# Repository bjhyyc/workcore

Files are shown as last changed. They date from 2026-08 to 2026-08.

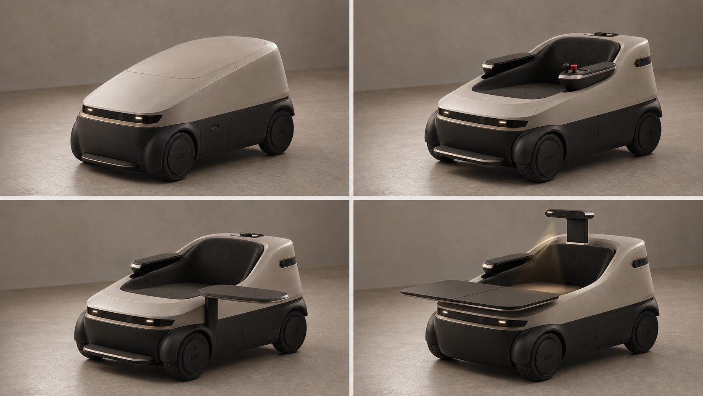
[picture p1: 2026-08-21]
design/e6_final_exterior/renders/02_four_state_board.png

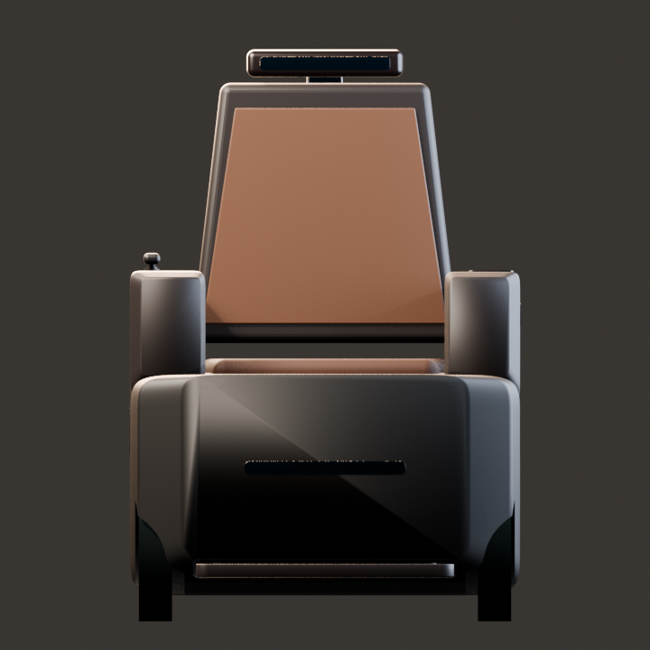
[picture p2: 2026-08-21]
design/e6_final_exterior/v11_v8_blender_exterior_restart_20260721/renders/preview/r14/ride/ride_front.png

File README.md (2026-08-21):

# WorkCore engineering CAD baseline

This repository converts the v30 and v37 WorkCore HTML concepts into a
parametric B-Rep CAD and system-engineering baseline. The generated STEP files
are intended for prototype engineering review and supplier discussion. They are
**not release-to-tool** drawings until the open assumptions, load cases,
tolerances, electrical architecture and safety analyses are signed off.

## Coordinate system

- Units: millimetres
- X: front/rear; negative X is the front/foot side
- Y: left/right; positive Y is the right side
- Z: height; Z=0 is the floor plane
- Assembly origin: floor projection of the chassis datum centre

## Build

```powershell
.\build.ps1 -Stage model
```

The wrapper requires Python 3.12, checks the CAD/runtime imports, rebuilds the
artifact set, then verifies its hashes and the requested gate. Use `-Stage evt0`,
`human`, `dvt`, `pvt` or `mp` only when intentionally testing that gate; a
non-zero result is expected while its evidence remains open.

Each build uses an empty `.build-staging/<run_id>/build` tree, so an old file
cannot satisfy a missing output. Publication is a journaled logical transaction:
the public status stays `PUBLISHING` while managed files are atomically replaced,
the manifest and hash-bound `COMPLETE` status are committed last, and a dead
publisher is rolled back before a later run proceeds. Unknown files under
`build/` are never deleted or packaged; the verifier reports them recursively.

Outputs are written to `build/`:

- `workcore_stowed.step` — transport configuration
- `workcore_follow_closed.step` — empty folded restricted-follow configuration with the restored v37 base sensor suite
- `workcore_obstacle_assist.step` — v37-derived rear pull handle extended with the unoccupied chassis pitched 8°
- `workcore_seat_ready.step` — occupied-ready seat and deployed footrest
- `workcore_cafe.step` — parked social configuration with one desk half deployed and the opposite side open
- `workcore_internal_layout.step` — shells removed for battery/data/compute/drawer review
- `workcore_transfer_ready.step` — right-side swing-away transfer configuration
- `workcore_desk.step` — forward-deploying dual-panel desk configuration with armrest lids closed
- `workcore_canopy_deployed.step` — canopy configuration
- `workcore_*.glb` — lightweight visual review models
- `workcore_desk_occupied_review.glb` — product plus clothed human keep-out model
- `workcore_e6_review.html` — single-file interactive four-state product and engineering review page
- `workcore_e4_review.html` — compatibility copy for existing bookmarks, presenting the same E6 review
- `workcore_e4_review_offline.html` — cache-busting, fully offline copy with embedded Three.js runtime
- `workcore_storage_review.glb` — dedicated shell-free equipment-bay review scene
- `workcore_storage_wheel_review.glb` — equipment-bay and wheel/suspension clearance context
- `workcore_electrical_thermal_review.glb` — electrical modules, PDU partitions, harness zones and heat-rejection context
- `parts/*.step` — supplier-facing individual solids
- `bom.csv` — material/process/mass estimate
- `production_bom.csv` — candidate configuration-union catalogue; not a released EBOM, purchasing list or unit-mass source
- `cots_interface_register.csv` — candidate supplier parts and controlled envelopes
- `tolerance_register.csv` — production-critical clearances and adjustment margins
- `validation.json` — geometry and clearance checks
- `engineering_report.json` — stability, wind, structure, actuator and load checks
- `mobility_report.json` — zero-turn, obstacle, access, elevator and trunk analysis
- `power_thermal_report.json` — traction/device power, energy, runtime, harness voltage-drop and airflow checks
- `production_readiness_report.json` — design-freeze evidence index, P0 gates and stage decisions
- `requirements_traceability.csv` — product, safety, usability and production requirements with evidence status
- `risk_register.csv` — system hazard register and required control verification
- `dvpr.csv` — EVT/DVT/PVT design-verification plan and acceptance intent
- `supplier_release_register.csv` — critical commodity selection and supplier-quality gates
- `production_gate_checklist.csv` — G0 through mass-production release checklist
- `access_scenarios.csv` — door and vehicle-template fit matrix
- `build_status.json` — generation state; interrupted/failed output is never packageable
- `release_manifest.json` — source/environment/artifact hashes, check split and stage decisions
- `preview_*.png` — rendered review images

## Engineering status

E6R2 is the current product-definition and CAD baseline. It restores the original
v37 folded follow-perception architecture as production-aware internal modules,
optical/RF/acoustic interfaces and real shell apertures. The user product has
four states: Follow, Ride, Café and Focus. Core width is now approximately
720 mm; the canopy is a detachable outdoor package; satellite communications
and onboard AC are removed; the four drawers are replaced by one 16-inch main
computer bay, one universal flat-device bay and an independent approximately
4.9 L daily-items caddy. E6R2 removes the false full-size travel cap so the
folded trapezoidal back itself becomes the weather cover, and turns the standard
right Café panel 90 degrees into a 430 x 270 mm transverse surface after the
drive pod is parked. Restricted following remains an empty, folded,
whitelisted-route Beta and is not a public-space autonomous-driving claim.

Revision E4 is a retained occupied-system geometry and safety input for East
Asian adults, not the current product baseline. E5 narrowed the launch market to
high-value knowledge workers in managed environments; its controlled B2B2C wedge
is retained by E6 while E5 product language remains design history. E4 adds closed armrest lids
in desk mode, a right swing-away transfer state, pelvic restraint, battery fire
isolation, 250 mm wheels, articulated side rockers, four-hub differential
zero-turn analysis, a 50 mm rated obstacle boundary, and door/elevator/vehicle
fit reports. Compact stow dimensions are recorded but do not override occupied
space or emergency egress.

E4-PWR1 adds a 51.2 V/30 Ah LiFePO4 design envelope, a 120 A continuous / 200 A
short-peak battery interface, separate traction and auxiliary contactors, dual
140 W USB-C PD, parked-only 600 W AC, a 90 W mast-device branch, zoned harness
routing and independent battery/electronics/laptop-bay thermal paths. All cell,
BMS, converter and fan part numbers remain supplier and prototype validation
gates.

E4-DFR1 adds physical package envelopes for the removable right-armrest drive control,
independent emergency stop, guarded charge/service-disconnect/manual-brake-release
interfaces, and an explicit production-readiness layer. The automated CAD checks
are intentionally reported separately from open regulatory, physical-test,
supplier and manufacturing gates.

E4-V37R restores three controlled features from the original v37 baseline:
the rear dual-tube obstacle-assist pull handle, the right-armrest removable
joystick/authorization pod, and the left-armrest status display plus 15 W Qi2
tray with FOD/temperature sensing. These are now CAD/BOM/validation items, not
render-only styling cues.

E5 is retained as design history but its managed-enterprise launch assumption is
superseded by E6. E5 had frozen the launch product thesis without replacing the E4 geometry baseline:
WorkCore is a personal embodied-AI work body for high-value knowledge work in
managed environments. The seat/chassis, hidden desk, asymmetric armrest HMI and
intelligence mast remain core; canopy, satellite communications, parked AC,
care claims and broad autonomy move to separately validated option packages.

The governing documents are:

- `docs/e6_product_definition_and_strategy.md` — current product constitution, four states, v37 follow-sensor restoration, storage decision, supply architecture and IP plan
- `docs/e6_launch_ecology_and_scenario_validation.md` — controlled launch wedge, real journeys, service/rescue model and pre-registered product evidence gates
- `docs/e6_object_character_and_mystery_brief.md` — new-object grammar, four-state expression, scenario behavior and falsifiable mystery/legibility gates
- `docs/configuration_control.md` — current-document precedence, evidence vocabulary and baseline rules
- `docs/configuration_mass_reconciliation.md` — pose-invariance audit, option deltas and EBOM identity closure criteria
- `docs/context_continuity_architecture.md` — measurable Context Continuity protocol, privacy boundary and EVT evidence plan
- `docs/e5_product_thesis_and_production_strategy.md` — frozen product thesis, launch scope, simplification rules, moat/IP plan and production convergence roadmap
- `docs/e4_product_definition.md` — target population, UX priorities and frozen E4 dimensions
- `docs/e4_p0_closure.md` — P0 design closures and mandatory physical release gates
- `docs/e4_access_transport_analysis.md` — elevator, shop, door and vehicle feasibility
- `docs/e4_internal_packaging_cmf.md` — laptop bay, internal modules, shells and finish maturity
- `docs/e4_power_energy_thermal_architecture.md` — complete power, energy, harness and thermal design envelope
- `docs/e4_design_freeze_readiness_review.md` — full industrial-design/NPD audit and production release sequence
- `docs/e3_human_centered_audit.md` — historical occupant-first audit and E3 findings
- `docs/v30_table_occupant_review.md` — coordinate-level review of the v30 desk
- `docs/e2_system_engineering.md` — historical E2 load boundary and prototype gates
- `docs/interface_control.md` — datums, supplier envelopes and rework controls
- `docs/safety_state_machine.md` — safe states and preliminary FMEA
- `docs/benchmark_matrix.md` — mature-product references and adoption limits

## Automated policy tests

```powershell
python -m unittest discover -s tests -v
```

These tests cover analytical units, quantity-aware mass, fail-safe motion
authority, Context Continuity privacy/safety policy, occurrence-identity rules,
controlled-overlap mutations, manifest integrity, concurrent publication,
failure rollback and dead-publisher recovery. They remain software and model
evidence only; they do not replace physical, supplier, regulatory or
manufacturing validation.

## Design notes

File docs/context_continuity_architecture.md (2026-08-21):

# WorkCore Context Continuity reference architecture

Status: E6 reference protocol and executable policy model for EVT software discovery. It is not production software, a security implementation or evidence that OS/application integration works. The reference implementation is `cad/context_continuity.py`.

## 1. Product purpose

Context Continuity is the reason WorkCore must be more than a powered chair with a folding desk. It binds an authenticated person, a known physical configuration, available devices, local task references, privacy state and optional network resources into a resumable work snapshot.

The measurable product moment is not “the mast moved”. It is:

> After the user parks and requests Focus or Café work, the correct local task becomes usable within P95 10 seconds, with no cross-user disclosure, no silent camera/microphone activation and no path from restore software to movement authority.

The 10-second target is a design input inherited from the E5 product thesis. Completeness/reliability targets must be frozen from task research before DVT; a fast but incorrect restore is a failure.

## 2. Hard boundary with movement safety

The continuity engine is outside the safety-control domain.

- It may read a hardware-certified summary such as `CAFE_PARKED` or `FOCUS_WORK`; it may not infer that state from UI intent.
- Restore is rejected unless the parking brake is confirmed, the drive contactor is open and relevant mechanisms are known and locked.
- It cannot request torque, reset STO, release brakes, move a table/mast/footrest or write safety-controller state.
- A failed, slow or compromised restore leaves the product parked. Physical escape and local manual controls do not depend on it.
- Every request and rejection is written to a tamper-evident product event stream in the production architecture.

## 3. Snapshot content and explicit exclusions

Allowed snapshot fields are opaque local workspace references, required device identities, optional network-resource references, the owner identity reference, source physical state, privacy requests, schema version and timestamp.

The snapshot must not contain plaintext credentials, encryption keys, raw biometric templates, reusable UWB secrets, safety-controller memory, arbitrary actuator commands or a serialized cloud session token. Production storage requires encryption at rest, authenticated records, per-user separation, rollback protection, retention limits and an export/delete/retirement path.

## 4. Restore sequence

1. **Authenticate owner locally.** A phone/UWB presence signal is not sufficient by itself for sensitive context release.
2. **Read the independent physical safety summary.** Unknown, moving or unlocked states reject restore.
3. **Validate snapshot schema, age and integrity.** Stale snapshots require an explicit user decision; future/invalid timestamps reject.
4. **Restore the local core first.** Network loss may remove collaborative/cloud resources but cannot erase the basic workspace.
5. **Reconnect only present, authorized devices.** Missing devices produce an explained partial restore rather than silent substitution.
6. **Apply privacy monotonicity.** The current, more private hardware state wins. A remembered camera/microphone use always requires fresh consent and visible indication.
7. **Measure and log.** Record authentication, gate result, start/useful timestamps, completeness, blocked items, user corrections and any cross-user/security event.

## 5. EVT scenario set

| Scenario | Expected result |
|---|---|
| Correct user, parked Focus, all local devices present | Full local restore; no motion request |
| Correct user, no network | Local task restores; network resources are explained as partial |
| Wrong or unauthenticated user | Reject before revealing task metadata |
| Ride/Follow/unknown mechanism state | Reject and remain parked/stopped |
| Snapshot requests camera but shutter is closed | Partial restore; shutter remains closed |
| Snapshot requests microphone without fresh consent | Partial restore; microphone stays unavailable |
| Required display/storage device missing | Partial restore naming the missing device; no silent reassignment |
| Snapshot older than the frozen retention/age boundary | Require explicit confirmation or reject |
| Power loss during snapshot write or restore | Recover last authenticated record; no corrupted half-restore |
| User export, deletion, service replacement or resale | Verifiable export/delete/crypto-erase with no recoverable prior-user context |

## 6. Required evidence

- Automated policy tests on every software change, including owner mismatch, unsafe state, stale/corrupt records, offline mode and privacy monotonicity.
- OS/device adapters tested against the frozen compatibility matrix, not merely the reference planner.
- At least one complete creator/developer task chain measured from park confirmation to useful work, with machine time separated from user cleanup/setup time.
- Repeated transition and interruption tests: sleep/wake, network switch, VPN, device removal, app update, compute-module reboot, OTA rollback and storage-full conditions.
- Threat modeling and penetration testing across phone/UWB identity, local APIs, cloud/API, debug/service ports, update and supply-chain boundaries.
- Human validation that partial restore messages answer “what is missing, why, and how to recover” without sending users into unsafe mechanism workarounds.

No claim of “context follows you” is releaseable until these tests have traceable reports and the product journey demonstrates that physical cleanup, doors, charging and recovery do not erase the promised time saving.

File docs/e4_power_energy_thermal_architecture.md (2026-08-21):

# WorkCore E4 电源、电量、线束与热管理架构

状态：E4-PWR1 工程设计包络。用于样机、电气原理图、供应商选型和测试计划；尚不是量产认证结论。

## 1. 设计结论

- 主电池：16S LiFePO4，51.2 V 标称、58.4 V 满充、30 Ah、1.536 kWh。
- 能量管理：日常按 80%（1.229 kWh）可用窗口计算，另保留 15%（230 Wh）安全/返航电量；安全控制器、通信与应急照明另有 24 V/60 Wh 独立电源。
- 主功率接口：电池 120 A 连续、200 A 短时；150 A 主熔断器；维修断电、预充、双接触器和母线电流检测必须位于电池之后、分支之前。
- 牵引：四个 250 mm 轮、25 N·m 连续和 70 N·m 峰值轮端转矩对应约 1.57 kW 连续、4.40 kW 峰值电输入。计入移动状态辅助负载后，峰值约 5.27 kW/103 A。
- 用户设备：双路 140 W USB-C PD；设备仓关闭时每路热降额至 100 W。600 W 纯正弦逆变器只允许停车态使用，以兼容 280–330 W 游戏本原厂电源。
- 外部供电：1.5 kW 外置充电器/底座，并提供岸电旁路。长时间桌面创作不应依赖加大车载电池解决。
- 桅杆：24 V/90 W 独立支路，覆盖 4K 相机、深度/红外相机、双补光灯、麦克风阵列、环境/状态传感器和网络桥；安全互锁双绞线与普通数据链路独立。
- 扶手HMI：12 V独立3 A支路，覆盖左侧5 W小屏、15 W Qi2和右侧摇杆/授权键；显示/Qi故障不得影响运动安全域。

## 2. 负载表

| 负载 | 连续/常用 | 峰值或额定包络 | 电源域 | 处理原则 |
|---|---:|---:|---|---|
| 四轮牵引 | 1.57 kW | 4.40 kW | 48V_TRACTION | 四路独立 40 A 保护；驱动故障不拖垮安全电源 |
| 双笔记本 USB-C | 200 W（仓内） | 280 W（仓开） | 48V_AUX → USB-C PD | 每仓 NTC 与风扇转速反馈；故障即停止充电 |
| 游戏本交流电源 | 0 W（移动禁用） | 600 W 逆变器 | PARKED_AC | 驻车、制动锁止并满足散热后才使能 |
| 机载计算核心 | 60–100 W | 100 W | 48V_AUX | 可覆盖 60 W 级 Jetson 模组及载板/存储/网络 |
| 通信 | 40 W | 100 W | 12V_AUX | 卫星发射突发与 5G 峰值纳入预算 |
| 桅杆小设备 | 80 W | 90 W | 24V_MAST | 7.5 A 独立保险；设备可逐级卸载 |
| 扶手小屏/Qi/控制 | 23 W | 30 W | 12V_HMI | Qi具备FOD、线圈温度和手机在位检测；过温独立停充 |
| 执行器/风扇/控制余量 | — | 300 W | 24V_AUX/12V_AUX | 动作互锁，避免与牵引峰值无约束叠加 |

桅杆 90 W 分配：4K 相机 12 W、深度/红外 15 W、两只补光灯 30 W、麦克风阵列 5 W、环境/状态传感 8 W、网络桥 10 W、设计余量 10 W。

## 3. 续航与充电

以下为 1.229 kWh 可用能量除以平均功率的工程估算，不含电池老化、低温与瞬态降额，必须用实际任务循环复测。

| 场景 | 平均功率 | 估算续航 |
|---|---:|---:|
| 安静办公 | 220 W | 5.59 h |
| 双设备创作 | 480 W | 2.56 h |
| 创作 + 间歇移动 | 650 W | 1.89 h |
| 高负载持续行驶 | 1.80 kW | 0.68 h |

1.5 kW 外置充电器按 92% 链路效率计算，10%–90% 理想能量时间约 0.89 h；含恒压收尾和温控后将产品目标定为约 1.2 h。充电口、电池接触器与岸电旁路必须互锁，禁止外部交流进入乘员可触及的低压设备仓。

## 4. 配电与保护

```text
16S LFP
  ├─ 150 A 主熔断器 ─ 维修断电 ─ 预充/双接触器 ─ 48V_TRACTION
  │                                              ├─ 4 × 40 A 电机控制器
  │                                              └─ 制动释放监控
  └─ 独立接触器 ─ 48V_AUX
                  ├─ 48→24 V / 750 W：桅杆、执行器、风扇、照明
                  ├─ 48→12 V / 240 W：通信、传感、音频
                  ├─ 双路 USB-C PD 140 W
                  └─ 600 W 纯正弦逆变器（仅停车）

24 V / 60 Wh 独立安全电源 → 安全控制器、通信、应急照明
```

负载卸载顺序：无线充电/装饰照明 → 交流逆变器 → 第二路笔记本快充 → 补光灯降亮度 → 非关键计算；牵引、制动、安全控制、最低通信和应急照明不进入普通舒适性卸载序列。

## 5. 线束路由

| 回路 | 铜截面 | 保护 | 计算压降 | 路由 |
|---|---:|---:|---:|---|
| 电池—PDU 主干 | 35 mm² | 150 A | 0.14% | 中央防护短隧道，先保险后接触器 |
| 单个轮端支路 | 6 mm² | 40 A | 0.38% | 左右门槛独立通道，轮端密封接头和滴水环 |
| 24 V 辅助主干 | 6 mm² | 35 A | 1.46% | 后部服务脊柱，星形分至桅杆、扶手和设备仓 |
| 24 V 桅杆支路 | 1.5 mm² | 7.5 A | 0.73% | 伸缩拖链，与屏蔽 Cat6A、安全互锁对线并行分仓 |

上述截面是当前长度、温升和压降的设计起点，不代替线材厂商载流量、束内降额、环境温度与连接器端子额定值。驱动电缆与麦克风/相机数据线平行时保持至少 50 mm 分隔，必须交叉时按 90°；轮端、抽屉和桅杆分别使用独立服务环，不允许靠自由垂落吸收运动。

桅杆拖链的最小动态弯曲半径按不小于成束外径 10 倍预留；样机须在全伸缩、折叠和顶棚展开的全部组合状态做夹线、拉力与视场检查。设备仓的充电线通过微型拖链进入抽屉，禁止跨越滑轨、锁舌和轮系扫掠区。

## 6. 热管理

### 电池区

电池使用密封结构盒、底部导热板和朝乘员舱外的压力泄放通道，不与乘员舱或电子仓共享空气。预设控制边界为：0°C 以下禁止充电、40°C 以上充电降额、45°C 以上禁止充电、50°C 以上牵引降额、55°C 包级停机；这些温度必须在电芯/BMS 选型后从供应商数据表重新冻结。低温仅用 100 W 受控加热片预热，不允许边加热边无监控快充。

### 电子区

按 210 W 需排出的热量、12°C 允许空气温升和 1.5 倍余量，最低风量为 46.1 CFM。方案采用两只带转速反馈的 30 CFM 鼓风机、密封循环风道和车尾鳍片换热器；单风扇故障时立即降低计算、USB-C 和通信负载，而不是继续满功率运行。

### 笔记本设备仓

左右仓各设独立迷宫进气、排风扇和 NTC。仓门关闭时每台限制 100 W；仓门打开、温度和风扇均正常时才放宽到 140 W。风扇停转、传感器断线或出口温升超限时关闭该仓充电。游戏本 330 W 原厂电源不得在关闭的笔记本仓内运行。

### 冷凝和进水

温湿度传感器维持至少 3°C 露点裕量；低压板件做选择性三防，连接器朝下或设滴水环，电子仓与电池仓各有独立排水路径。进气过滤器必须可从外侧免工具更换，不能要求拆座椅维护。

## 7. 供应商与样机放行门

1. 冻结电芯/BMS，并实测 120 A 连续、200 A 短时、短路保护、热传播和泄压方向。
2. 在 40°C 环境、双仓各 100 W、计算和通信满载条件下做稳态热平衡。
3. 桅杆和抽屉线束全行程寿命试验，复核最小弯曲半径、端子拉力与磨损粉尘。
4. 四轮原地转向时同时运行相机、麦克风、5G/卫星和补光灯，完成传导/辐射 EMC 测试。
5. 完成适用的载人移动设备电气、环境、充电和功能安全合规评审；当前模型不构成认证。

## 8. 选型依据

- USB-IF：USB Power Delivery 3.1 EPR 支持最高 240 W，当前方案为热管理和多端口总功率选择 140 W/口，而非把 240 W 当作默认。[USB-IF USB PD](https://www.usb.org/usb-charger-pd)
- Apple 当前 16 英寸 MacBook Pro 配 140 W USB-C 电源、100 Wh 电池，作为高功率创作本边界之一。[MacBook Pro 技术规格](https://www.apple.com/macbook-pro/specs/)
- ASUS ROG 原厂游戏本适配器为 330 W，证明只做 USB-C 不能覆盖全部目标用户。[ROG 330W 适配器规格](https://rog.asus.com/us/docks-chargers-and-cables/chargers/rog-330w-dc-adapter/spec/)
- NVIDIA Jetson AGX Orin 模组功率范围为 15–60 W，机载计算 100 W 包络另包含载板、存储、网络和散热余量。[Jetson AGX Orin 技术简介](https://www.nvidia.com/content/dam/en-zz/Solutions/gtcf21/jetson-orin/nvidia-jetson-agx-orin-technical-brief.pdf)
- Qi2 的 15 W 级互操作充电可作为手机便利功能，但不进入关键任务电源。[WPC Qi2](https://www.wirelesspowerconsortium.com/standards/qi-wireless-charging/)
- IEEE 802.3bt 的 PSE 最高 90 W、PD 最高约 71.3 W，桅杆网络可采用标准化 PoE 管理，但本方案仍给安全互锁保留独立线对。[Ethernet Alliance 802.3bt 设计资料](https://ethernetalliance.org/wp-content/uploads/2022/10/PD-Design-for-Conformance-and-Interoperability_07AUG22.pdf)

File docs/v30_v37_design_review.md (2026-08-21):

# WorkCore v30 to v37 engineering design review

> 本文件记录早期架构取舍。桌板载人结论已由 `v30_table_occupant_review.md` 和 `e3_human_centered_audit.md` 替代；E2 的桌板位置已判定失败。

## Source control

- v30 source: `WorkCore-3D-v30-HiddenCanopy.html`
- v37 source: `WorkCore-3D-v37-ArmrestChamfer.html`
- v37 SHA-256: `9BF0082E69A980CFCD542B6A91E213D47E82724D179BD90BEF0155125F300877`
- Review basis: program geometry and state logic.  The HTML is a visual mechanism
  demonstrator, not a tolerance-controlled CAD definition.

## Decisions

| v37 change | Decision | Engineering reason / E2 correction |
|---|---|---|
| Fixed back hinge with armrest inner chamfer | Adopt | Fewer moving datums and no sliding hinge hardpoint. Rebuilt as B-Rep solids and checked against the folded back, instead of trusting the `8 mm` source comment. E2 实测扫掠最小间隙为 13.546 mm。 |
| Armrest integrated down to the body | Adopt architecture | Removes the v30 floating support and makes the side module a structural/service carrier.  E1 uses a hollow replaceable shell located from chassis datums. |
| Full-length armrest lid | Adopt | Better service access and enough opening to remove the stored table module.  Production version needs a positive latch, seal, open stop and drain strategy. |
| Upright-fold 430 x 260 mm side table | Adopt with changes | Packaging is better than the v30 diagonal cantilever.  E1 changes the 10 mm stainless plate to a light aluminium honeycomb sandwich panel and adds positive centre latches. |
| Fixed 805 mm table surface | Reject | Too high for the published 559-762 mm seated keyboard range.  E1 uses 750 mm as the packaging target; final production should provide adjustment or target-population evidence. |
| Armrest top at 685 mm with original 580 mm seat top | Reject | About 105 mm support height is below the 178-267 mm workstation target.  E1 uses a 550 mm seat top and 735 mm armrest top. |
| Commented `zero-interference` claim | Reject as evidence | Three.js does not run a swept-volume or tolerance check.  E1 performs solid intersection checks and will add an 8 mm clearance envelope after kinematic hardpoints are frozen. |
| Cover/table hard interlocks | Adopt | The cover must be open before table motion and cannot close until the table is stowed.  This becomes a dual-channel position/latch requirement, not only animation ordering. |
| Qi phone soft interlock | Correct | v37 opens lids in mode 8 but hides the phone only in modes 4 and 5.  Production logic must sense occupancy and either inhibit lid motion or command a user-visible removal step in every affected state. |
| `trapN` helper | Do not adopt | It is defined in v37 but the actual back still uses `trap`; it provides no production geometry in that revision. |

## E2 user-experience baseline

- Seat top: 550 mm with a mandatory integrated footrest because this remains a high seat.
- Usable seat depth: 430 mm; width: 560 mm; waterfall front edge required.
- Armrest support height: 185 mm above compressed seat.
- Desk surface: 750 mm; two 430 x 260 mm halves meet into a 430 x 520 mm surface.
- Each table half target mass: under 1.5 kg before hinges/latches.
- One-hand user effort target: no more than 22.2 N at handles; assisted motion must not
  create an uncontrolled closing load.
- No structural state may depend on a friction hinge alone.

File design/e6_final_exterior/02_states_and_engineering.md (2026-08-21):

# 02 — 四状态与工程边界

## 不可越界的工程事实

以下数据来自现有产品定义/CAD，应在下一阶段以最新接口控制文件复核：

- 核心长度约 790 mm，体宽约 720 mm，当前总宽约 735 mm；收纳目标小于 900 × 760 × 700 mm。
- 四轮约 Ø250 × 64 mm；固定壳与运动轮胎必须保留运行间隙，接地真相不可被遮蔽。
- 座面约 470 × 590 mm，顶面约 500 mm；扶手顶约 680 mm。
- Focus 双桌各约 430 × 270 mm，桌面高约 705 mm，中心缝目标 12 mm。
- 脚踏约 540 × 250 mm，展开高度约 70–130 mm 可调。
- 桅杆外套约 70 × 136 mm、行程约 420 mm；Ride/Café 保持低位，Focus 且驻车后才可升高。
- 必须保留低位导航感知、右侧驾驶控制、左侧显示/Qi、实体隐私片、机械急停、服务/恢复侧和无电释放路径。

若外观超出既有包络、改变门宽/回转、传感视场、轮胎间隙、人体扫掠或散热泄压，必须重新触发对应 ODD、动力学、安全与法规验证，不能视为纯造型修改。

## Follow — 闭合与方向

**视觉目标**：像一件不会被误提、误坐或误认为行李的低位完整物品。

- 顶面完整闭合；座、桌、脚踏与桅杆不以临时托盘或拉杆形态外露。右侧控制 pod、直立摇杆与授权键四态固定在同一前置扶手顶端并始终外露，Follow 仅撤销牵引授权，不得将其收纳、后移或折平。
- 感知地平线保持低位；前向短光标与前后体量差表达运动方向。
- 四轮接地可读，重心稳定，不悬浮、不拟人。
- 所有会运动的上表面缝在静态时贴合成一个连续秩序。

**必须复测**：坡道/门槛/地毯与轮拱间隙、传感视场、近场儿童/宠物可见性、触边覆盖、倾覆、制动、声光意图、雨水与污物路径。

## Ride — 人是主体

**视觉目标**：E6 提供支持，但不把乘员吞入驾驶舱。

- 座椅、脚踏和扶手从同一壳体中自然显露；低靠背/低脊柱保持开放视野。
- 右侧控制、左侧信息的不对称语义保留；急停对乘员和助手均可达。
- 外壳不过肩、不高包围；软包无医疗绗缝和赛车桶椅感。
- 桌不部署，桅杆保持低位，乘员仍是轮廓和照片中的视觉主体。

**必须复测**：第 5/50/95 百分位人体、转移路径、手肘/膝/足扫掠、约束与离开、操控可达、急停可达、夹点、振动、热舒适、清洁消毒。

## Café — 对面的人有位置

**视觉目标**：一侧主动打开形成邀请，而不是一张坏掉的半桌。

- 仅一片桌叶依照“前移—旋转—回位”展开；开放侧从正面和斜侧一眼可读。
- 驻车后撤销驾驶授权，但右侧控制仍固定在扶手前端、外露且手部可达；桌板不得遮挡、跨越或迫使控制后移。
- 低脊柱不升高，不在两人之间形成摄像头压迫感。
- 桌缘、坐姿和开放带构成面对面的社交关系。

**必须复测**：对坐膝部/脚部空间、开放侧通行、桌面载荷/倾覆、杯具滑落、夹点、驻车互锁、误触控制、桌面清洁和液体排水。

## Focus — 显露能力但不封闭人

**视觉目标**：双桌形成精确工作面，窄脊柱只在需要时上升，建立边界而非驾驶舱。

- 两片桌叶形成同一平面；中心防夹缝精确、克制且可清洁。
- 观测脊柱先确认驻车与净空再升起；薄型观测檐保持头部空间。
- 实体隐私片的开/关状态不依赖屏幕；任务灯只照向工作面。
- 不用巨大屏幕、环舱围板或灯光把乘员包装成展品。

**必须复测**：桌面平面度与刚度、锁止、断电释放、头部净空、升降夹点、相机视场/隐私片、照度与眩光、线缆/杯具、热管理、长时人体工学。

## Outdoor Pack — 附件，不是第五人格

顶棚和环境附件必须可拆、可排水、可维护、可紧急回收；装上后仍属于同一几何家族，但不能让主机长期像带方杆的临时雨棚。安装后需重新验证风载、侧倾、净高、感知遮挡、排水、手动回收与运输包络。

## 表皮建模规则

- 现有 STEP 是只读硬点 underlay；新 Class-A skin 必须另建文件与装配层级。
- 先建立轮胎、人体、桌/脚踏/桅杆运动扫掠和传感锥的禁止侵入体，再做外表面。
- 可彻底重塑当前方箱、传感彩块、外露滑架、粗方柱、T 梁、扶手高墙、平板顶棚和工程识别色。
- 不能以一个不可拆的光滑罩壳封死服务、散热、泄压、排水、清洁或无电恢复。

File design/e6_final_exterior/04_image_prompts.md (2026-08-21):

# 04 — 概念图生成提示词

以下提示词锁定同一产品身份。图像用于造型方向沟通，不替代尺寸、结构或法规证据。

## 统一正向核心

```text
WorkCore E6 final production-intent Class-A industrial design, a genuinely new personal field instrument rather than a beautified prototype, preserve the engineering architecture and realistic human scale: low approximately 790 mm long and 735 mm wide core, four 250 mm wheels partly integrated but with visible tire contact, seat opening, footrest, armrests, desk kinematics, HMI, low sensor hardpoints and rear telescopic intelligence spine. Quiet retro-futurism, late-1960s orbital research instrument reinterpreted as contemporary premium furniture, soft trapezoidal superelliptic planform, low monolithic mineral base, seamless nested shells, taut smooth manufacturable surfaces, disciplined radius hierarchy, warm lunar-stone microtexture upper shell, deep smoked-umber segmented sensor horizon, satin champagne anodized aluminum micro-reveals, charcoal-brown removable 3D-knit upholstery, espresso matte desktop, sparse warm-white and amber functional light glyphs, unmistakable physical camera privacy shutter, subtle readable front and rear direction, hidden mechanisms, controlled shadow gaps, flush rear service door, replaceable lower scuff strip, realistic PC-ABS, coated aluminum, TPE seals and drain paths. Calm, minimal, premium, mysterious capability but unambiguous intent, photorealistic industrial design studio render, physically plausible manufacturing, no branding or text.
```

## 主视图补词

```text
RIDE state hero, front-left three-quarter eye-level view, integrated seat and horizontal footrest emerge from the same continuous shell, low back spine, right-hand physical control pod subtly visible, real red emergency stop reachable but not visually dominant, desk fully stowed, person absent so the object silhouette can be judged, neutral warm-grey seamless studio, large softbox reflections revealing smooth Class-A curvature, 50 mm lens, product occupies most of frame.
```

## 四状态板补词

```text
One consistent WorkCore E6 shown in a precise 2 by 2 state study, same camera, scale, lens, materials and lighting in every cell, no labels or text. The same upright right-hand joystick, control pod and authorisation key remain visibly fixed at the forward armrest-top hand station in every cell; only Ride enables traction, and no deployed desktop may cover or move them. Top-left Follow: completely closed quiet low object, no visible seat tray, deployed mast or pull handle. Top-right Ride: seat, low back, armrests and footrest emerge, desk stowed, occupant remains conceptually primary. Bottom-left Cafe: exactly one desktop glides and rotates outward while leaving the forward control island clear, opposite side visibly open and welcoming, parked and low spine. Bottom-right Focus: paired desktops form one precise work plane without hiding the forward control island, narrow observation spine rises only while parked, thin sensor visor, physical privacy shutter clearly closed, directed task light, no cockpit enclosure. Clean generous gutters, orthographic-like three-quarter product design board.
```

## CMF/细节板补词

```text
Premium industrial design CMF and functional detail board for the exact same WorkCore E6, one large three-quarter close product view plus restrained macro crops: warm lunar-stone microtexture shell meeting smoked-umber real sensor materials; satin champagne anodized micro-reveal; charcoal 3D-knit removable upholstery; espresso anti-fingerprint desktop edge; thin observation visor with unmistakable sliding mechanical privacy shutter; two short directional light glyphs; reachable real red mushroom emergency stop; flush stern service door with captive fastener logic; replaceable TPE wheel-arch scuff strip and visible drainage lip. Museum-grade neutral studio lighting, realistic texture scale, engineered gaps, no swatches with text, no decorative props.
```

## 统一负向约束

```text
prototype CAD blocks, stacked boxes, server rack, tool cart, wheelchair, hospital equipment, mobility scooter styling, luggage, office chair, gaming chair, delivery robot, robot face, eyes, anthropomorphic expression, cyberpunk, steampunk, military, aggressive automotive grille, glossy white appliance plastic, piano black, chrome overload, fake woodgrain, RGB strips, decorative breathing lights, giant screen, dominant T-shaped mast, exposed actuator, exposed cable, exposed hinges, trays left open in Follow state, random seams, colored sensor stickers, fake continuous black sensor glass, decorative vents, inaccessible sealed monocoque, impossible floating surfaces, razor-thin panels, hidden tire contact, enclosed occupant cockpit, medical quilting, excessive branding, unsafe ambiguous motion direction, captions, labels, logos, watermark.
```

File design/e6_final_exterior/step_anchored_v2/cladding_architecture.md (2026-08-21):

# Class-A 外覆架构

原则：STEP/GLB 是工程内核、功能硬点和机构扫掠，不是最终可见面的逐件清单。最终产品必须通过少数可拆外覆件，把“零件森林”收敛成一个新物品；包覆不能以移动硬点、封死服务或侵入扫掠为代价。

## A — 下部核心舱

**应包覆**：底盘侧梁、下部零散板件、设备仓周边毛边、摇臂连接视觉噪声、非操作紧固件和局部支架。

**外覆策略**：以左右两片主侧壳 + 前触边/感知鼻 + 后服务艉门 + 可换下缘耐撞条组成低位连续体。侧壳使用长弧面和低曲率变化，不做汽车翼子板；轮胎通过精确的圆角开口穿出，保留至少工程运行间隙和完整接地可见性。

**必须开放**：前双 ToF、腿扫、触边、侧超声换能器面、RF/声学透过区、四角下视窗、散热/泄压、排水、充电/制动释放/维修断电及后服务门。

## B — 轮组与侧裙

**应包覆**：轴端周围非维护结构、摇臂/连接部的视觉噪声与泥水直视路径。

**外覆策略**：使用固定在车体上的低位“桥式侧裙”和独立可换轮缘护片；它们跟随车体而不是随轮转向。轮胎上半部与内侧机构必须被壳体连续吸收，不得形成汽车式前后轮拱或暗示转向节。大面积外侧皮只保留 `z=0–32 mm` 低位接地条，几何门必须证明侧面 `z=20 mm` 开放而 `z=55 mm` 闭合；仅前后纵向端回保留局部 `z=0–70 mm` 运动/排水让位，并证明端部 `z=55 mm` 开放而 `z=90 mm` 闭合。每个前/后端回外侧另设一件 `1.0 mm` 月岩体色可换冲击皮，与深色结构端回保持 `0.1 mm` 干隙并覆盖 `Y=88.6 mm、Z=71–314 mm`；深色结构件不能直接成为正/后视的可见完成面。端回让位不得扩展为差速轮整体外露。

**必须开放**：下部接地带、轮胎变形、110 mm 轮端维护拆轮路径、悬架全行程和泥水排出；不得把维修口扩大为半轮或整轮可见。

## C — 扶手 / HMI / 桌舱

**应包覆**：长扶手内部桌板收纳束、导轨、锁止件、线束、铰接与外露框架。

**外覆策略**：每侧一件连续长壳，保留约 520 mm 的真实长度；上盖为柔和触摸面，下壳为承力视觉体，之间只有一条可追溯变形缝。右侧控制 pod 从齐平凹槽显露；左侧显示/Qi/急停形成明确但不喧宾夺主的触点岛。Café/Focus 桌叶从这条真实桌舱缝中运动。

**必须开放**：右摇杆/授权、左显示/Qi/机械急停、桌叶扫掠、夹点防护、无电释放、液体排水与换件入口。

## D — 座椅 / 靠背 / 折叠天气盖

**应包覆**：梯形靠背承力架、三角支撑视觉噪声、占用/约束周边非接触结构与折叠铰链非操作部分。

**外覆策略**：前面是可拆 3D 针织接触件；后面是一件具有真实内腔、名义壁厚 4 mm 的完整梯形精密壳，侧边形成连续“脊线”。Ride 中它仍是清楚的梯形靠背，不变成桶椅；Follow 中同一后壳绕真实铰轴翻下并成为唯一天气盖，物理件守恒。根部由四态固定的左右 A04 空心根肩闭合，不得另造状态专用 A06 cheek。

**必须开放**：人体离开路径、约束锚点/检查、占用传感、铰轴运动缝、排水、清洁拆卸与头部净空。

## E — 脚踏及部署支撑

**应包覆**：两条部署支撑、锁止和线性导向的外露机械外观。

**外覆策略**：使用唯一 `210 × 500 × 10 mm` 平台定义与同一左右支撑/护套/正锁总成；Ride 展开时以连续浅色薄壳、内嵌深色踏面、左右运动 monocoque 与根部开底壳闭合。Follow/Café/Focus 收纳时，同一平台回到 `X≈-360, Z≈147 mm`，左右护套竖直收进已闭合的光学鼻腔，不删除零件、不换一块假踏板。护套必须随真实 21 点扫掠退让，不能用固定保险杠遮住机构。

**必须开放**：足部空间、锁止确认、无电释放、夹点控制、前感知视场、排水与清洁。

## F — 桅杆与智能梁

**应包覆**：外管/内管、导向、线束与执行器的零件感。

**外覆策略**：后中形成一根窄、连续的“观测脊柱”，由同一固定套筒、一件完整移动脊柱和同一冠梁构成；禁止 `stage_2/stage_3` 行李拉杆语法。Ride/Café 保持同一低位感知地平线；Focus 只让移动脊柱、冠梁及其功能件上移 420 mm，固定套筒不动并保持至少 150 mm 捕获；Follow 中低态总成与 A06 共用同一铰链折叠。脊柱—冠梁使用 16 mm 隐藏榫槽、3 mm 径向装配间隙、2 mm 端余隙和 4 mm 外观干缝，不以零距离端面假装连接。

**必须开放**：烟熏传感窗、126 × 34 mm 实体隐私片、麦克风/灯、导向间隙、头部净空、散热与维修。

## G — Café / Focus 桌板下表面

**应包覆**：升降柱、yoke、旋转轴承、导轨和锁止件在正常使用视角下的零散机械面。

**外覆策略**：桌叶保持 430 × 270 × 12 mm 物理件及真实运动，以下表面薄型护罩、圆角边带和靠近扶手的“根部胶囊”组织机构；机构只在动作瞬间有限显露。

**必须开放**：全部扫掠、中心防夹缝、锁止/释放、杯具/线缆边界、排水与维护入口。

## 视觉连续性

- 主壳只使用三条可见逻辑线：下部感知/耐撞线、扶手/上甲板变形线、后服务线。
- 包覆件不能彼此融成不可拆大壳；装配缝沿真实模块边界并服务于维护。
- 复古科幻来自“精密仪器式壳层 + 真实机械仪式”，不是把样机零件涂成米白色，也不是另造一辆汽车。

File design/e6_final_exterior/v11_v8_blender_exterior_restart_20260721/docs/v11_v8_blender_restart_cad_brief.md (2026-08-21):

# WorkCore E6 V11 V8 Blender restart — CAD and visual brief

## Classification

- Model: WorkCore E6 four-state exterior/layout assembly.
- Task type: source modification and visual surface restart from immutable V8
  state geometry; Blender is the visual decision model, not the production
  STEP release.
- Source: four clean V8 `workcore_e6_class_a_<state>.glb` files.
- Excluded sources: all V9/R09 and V10 visual meshes, proportions and probe
  geometry.
- Units: 1 Blender unit = 1 metre; engineering reports use millimetres.
- Coordinates after the single import correction: front `-X`, rear `+X`, left
  `-Y`, right `+Y`, up `+Z`.

## Design objective

Create one quiet, low, complete and mysterious new object.  It must not read as
a wheelchair, office chair, tool cart, suitcase or exposed robot chassis.
Retro-futurism comes from proportion, continuous volume, precise functional
seams and real materials, not decoration or exposed mechanisms.

## Immutable product DNA and hardpoints

- A06 retains its iconic front-view trapezoid.
- Follow uses that same A06 as its only folded upper surface; no hood, box lid,
  skirt or filler surface is permitted.
- A07 remains one externally recognisable tapered mast in every state.  Ride
  and Cafe share the low pose; Focus translates the same moving mast/head by
  `+420 mm Z`; Follow folds A07 with A06.
- Both armrests are fixed continuous bodies; there is no side-opening armrest.
- The right joystick and authorisation control remain exposed on the forward
  right armrest top in all four states.
- The display is one `124 x 49 mm` layer, tilted about world Y by `8 degrees`,
  front high and rear low.
- Cafe deploys the right table only; Focus deploys both tables.  Deployed table
  surfaces remain inboard of the armrest inner faces and never cover the
  joystick.
- Ride footrest is deployed by default; Follow, Cafe and Focus are stowed by
  default.
- Differential wheels are partially absorbed by the body mother surface.  No
  separately readable fender is allowed.
- A04 battery/equipment door remains `464 x 86 mm R18` in a
  `466 x 88 mm R19` opening, with a nominal `1 mm` seam and `300 mm` service
  travel.
- Overall finished width remains at or below `752 mm` until an engineering
  change is explicitly approved.

## P0 exterior work

1. Rebuild the lower body as one continuous mother surface joining front nose,
   belly, side shoulders, equipment door and wheel half-wrap.
2. Re-solve Follow closure using the A06/A07/seat/armrest physical pieces.  It
   may have a controlled slope; it need not be mechanically flat.
3. Rebuild armrest proportions and the top interface as one hierarchy while
   preserving the control, display, charging and table-cassette envelopes.
4. Reduce parting lines to real motion, service, sensing, drainage and safety
   boundaries.
5. Freeze a restrained CMF: dark mineral low-gloss body, real leather contact
   surfaces, natural walnut veneer and limited brushed 316 stainless detail.

## Validation targets

- Four states are generated from the same named design parameters and shared
  source functions; there are no state-specific cosmetic cover parts.
- V8 input byte counts and SHA-256 values match the locked baseline before each
  build.
- The one-time GLB axis correction is exactly `Rx(-90 degrees)` with no scale
  correction.
- Wheels, joystick, authorisation control, emergency stop, display face, seat
  contact, A06/A07, tables, footrest and service interfaces remain traceable by
  original V8 occurrence ID.
- Baseline and every accepted visible revision receive front, rear, left,
  right, top and hero visual checks; Follow receives additional high-front and
  rear-oblique closure checks.
- Blender approval does not claim Class-A, manufacturability, motion safety or
  production release.  Accepted visual geometry must be rebuilt in the
  canonical V8 STEP/B-Rep pipeline and all affected gates rerun.

## Output paths

- Reference master: `blender/e6_v11_v8_locked_reference_master.blend`
- Visual revisions: `blender/e6_v11_visual_rXX.blend`
- Source reports: `qa/`
- Preview renders: `renders/preview/`
- Formal renders after STEP round-trip: `renders/final32/`

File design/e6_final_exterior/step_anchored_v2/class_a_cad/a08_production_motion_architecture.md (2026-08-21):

# A08 production-motion architecture — release blocker and replacement datum

Status: **P0 / NOT RELEASED / not a production certification**

This note replaces the non-physical interpretation of the current A08 motion.
It does not authorise a render or STEP release by itself.  The geometry, locks,
tolerance stack, proof load and safety circuit still have to pass the gates at
the end of this document.

## Why the current mechanism is blocked

- At 101 equally spaced samples, the current platform and moving supports have
  hard common volume from progress `0.81` onward.  The largest measured
  platform-to-one-boot common volume is `17,272.5 mm3` at progress `0.84`.
- The stowed straight support ends are `(x=-400, z=152.5/287.5) mm`; its
  deployed ends are `(x=-605/-470, z=110) mm`.  The closest endpoint moves
  `82.5 mm` including the released lateral shift.  It is therefore not a rigid
  arm rotating about a fixed hinge.
- No captured guide, carriage or four-bar occurrence exists to carry that
  moving support.  The current interpolation is a floating body, not a load
  path.
- The final `A08_footrest_root_monocoque` and two
  `A08_footrest_support_monocoque_*` occurrences exist only in Ride.  Hidden
  stowage may change a transform or visibility, but may not delete physical
  parts.
- A Café/Focus user's normal floor-position shins enter the current deployment
  sweep from progress `0.12`; one shin reaches `216,984.51 mm3` common volume.
  The seat occupancy mat cannot prove that the foot zone is clear.

## Selected replacement architecture

Use a twin captured telescopic drawer with a paired over-centre drop link on
each side.  It preserves the existing horizontal platform endpoints without a
free-flying support:

| Datum | Stowed | Deployed and positively locked |
|---|---:|---:|
| platform centre X | `-360.000 mm` | `-605.000 mm` |
| platform centre Z | `147.000 mm` | `95.000 mm` |
| platform pitch | `0 deg` | `0 deg` |
| platform outer size | `210 x 500 x 10 mm` | same physical occurrence |
| lower carriage pivot Z | `80.000 mm` | `80.000 mm` |
| drop-link pin length | `62.000 mm` | same physical occurrence |

The two body-fixed rail housings capture a primary moving cartridge and an
inner carriage.  The cartridge and inner carriage may translate only along X;
they cannot translate freely in Y/Z or rotate.  Two identical drop links on
each side form a parallelogram, so the platform stays horizontal.  A cross-shaft
synchronises left and right links.

The exact one-degree-of-freedom law is:

1. **Tactile-edge clearance, 0–10 %:** each `62 mm` drop link rotates from
   `0 deg` to `44.791325 deg` from vertical while the captured inner carriage
   retracts `43.680659 mm` into the body.  Those two X motions cancel, so the
   platform stays at `X=-360.000000 mm` and descends `18 mm` to `Z=129 mm`.
   The final tread's highest point is then `Z=143 mm`, a real `5 mm` dry gap
   below the tactile bumper's `Z=148 mm` lower datum.
2. **Captured drawer extension, 10–70 %:** hold the link angle.  From its fully
   retracted clearance position, the primary cartridge travels `144.000000 mm`
   and the captured inner carriage travels a further `83.492425 mm`.  The
   platform reaches `X=-587.492425 mm`, `Z=129 mm`.  Every rail stage retains
   at least `25 mm` overlap at maximum extension.
3. **Over-centre drop and lock, 70–100 %:** the links rotate to
   `80.718201 deg` from vertical.  Their horizontal component becomes
   `61.188234 mm` and their vertical component becomes `10.000000 mm`, placing
   the platform exactly at `X=-605.000000 mm`, `Z=95.000000 mm`.

The reverse path is mandatory for stowage.  The initial inward carriage motion
is not optional: omitting it makes the raised final tread swing through the
tactile bumper even though the older flat structural proxy appears clear.  No phase may be skipped, blended
through another part, or replaced by endpoint interpolation.

## Physical occurrences that must never disappear

- platform top, tread and perimeter occurrences;
- fixed root monocoque/housing;
- left and right primary support monocoques/cartridges;
- left and right captured inner rail stages;
- four drop links, eight replaceable plain bearings and their guarded pins;
- left/right deployed rail lock pins and independent lock witnesses;
- synchronising cross-shaft, counterbalance spring and manual release cable;
- body-side manual release paddle.

The fixed root monocoque remains attached to A01 in all states.  The two smooth
support monocoques translate through dry apertures into the body when stowed;
they do not rotate upright or vanish.  Internal load rails sit at `Y=+/-220 mm`
and below the platform.  Cosmetic support monocoques sit outboard of the
platform edge with a minimum `4 mm` dry split during the final drop, so an
unseen Boolean pocket is not used as a collision allowance.

## Preliminary load-path sizing (design input, not certification)

- analytical vertical proof-load input: `1.5 kN` distributed, `0.75 kN` per
  side;
- approximate per-side cantilever moment at the existing endpoint:
  `101.25 N m`;
- candidate nested 6061-T6 rail sections, outer to inner:
  `30 x 40 x 3`, `26 x 34 x 3`, `22 x 28 x 3`, `18 x 22 x 3 mm`;
- corresponding simple elastic bending stresses under the full per-side moment
  are approximately `24.9`, `35.4`, `54.4`, and `93.8 MPa` before joint,
  impact, fatigue or stress-concentration factors;
- minimum deployed stage overlap: `25 mm`; minimum dry running gap: `3 mm`;
- the endpoint load bypasses the actuator through two mechanical rail pins and
  two over-centre link locks.  The actuator/counterbalance may not be the sole
  occupant-load path.

FEA, pin bearing, tube crippling, link buckling, fatigue, abuse load, corrosion,
contamination and physical proof tests remain open.

## Required safety sequence

Optional Café/Focus opening is permitted only after all of the following are
true: speed zero, park brake proved, traction STO proved, table sweep clear,
two-channel foot-zone clear proved, user makes a deliberate request, and the
manual release is held.  Drive remains inhibited until both deployed lock
witnesses agree.  A seat mat alone is explicitly insufficient.  Loss or
disagreement of either foot-zone channel prevents powered release and leaves
the mechanism in its last mechanically locked state.

## Gates required before final renders

1. Same complete occurrence inventory at all 101 poses and both endpoints.
2. Inverse-transform B-Rep identity for every rigid occurrence; no volume-only
   substitute test.
3. Moving-vs-fixed, moving-vs-moving, human foot/shin and ground swept-volume
   checks at 1 % increments plus adaptive subdivision below `5 mm` clearance.
4. Zero hard common volume, except pins/bearings represented as explicit joint
   interfaces; no allow-list for platform/support overlap.
5. Minimum `3 mm` dry clearance through the complete tolerance stack and at
   least `25 mm` rail-stage overlap at maximum extension.
6. Independent proof of the two deployed rail pins, two over-centre locks,
   stowed lock, manual no-power recovery and two-channel lock sensing.
7. Physical instrumented proof-load, abuse, contamination, pinch, wet, drain,
   fatigue and emergency-recovery tests.

Until all seven gates pass on the final V8 B-Reps, A08 remains a release
blocker and must not appear in a claimed final 32-image series.

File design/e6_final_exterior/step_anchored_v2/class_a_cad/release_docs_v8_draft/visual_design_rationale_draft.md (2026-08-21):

# WorkCore E6 V8 最终外观设计依据（草案）

文档状态：`V8 最终外观候选依据源；正式数字制品状态以同版 manifest 与 BUILD_INCOMPLETE 是否存在为准`

视觉设计约束状态：`V8 外观语法已冻结；数字制品是否完成由正式几何、raster 与 artifact-closure 报告判定`

Class-A 放行状态：`NOT RELEASED / TBD`

## 1. 设计命题

V8 的目标不是把轮椅、桌子、跟随箱、机器人和屏幕做一次视觉拼接，而是让同一个物品根据人的任务改变边界。闭合时它应安静地保留能力；人进入后，控制权围绕人建立；驻车后，才展开社交或专注所需的物理边界；身份、隐私和设备条件成立后，数字任务才恢复。

因此，“新物品感”来自状态之间有因果的转化，不来自增加一块屏、一个拉杆或一套装饰灯。“神秘感”来自能力尚未显露，但运动、安全、隐私、故障和接管意图必须明确。

## 2. 五条恒定外观语法

### 2.1 低而完整的核心体量

下部 A01–A04 形成稳定、连续、有重量的核心，不把轮组和承力架读成工具车底盘。A01 在四态中以同一件永久 brow-and-crown 前鼻天气面闭合感知地平线上方的脚舱视线，不让正常站立或斜上视角穿入内部，同时从乘员侧保留真实脚部通道。差速轮的上半部与传动区由连续轮罩和 rocker 外皮吸收，只保留下部接地胎面、运动间隙和轮端维修口；不用整轮外露，也不用悬浮裙边伪造运动关系。

数字几何完整性：`以正式 manifest 引用的几何、碰撞、raster 与制品闭包报告为准`。

实体比例、接地读感与旁观者判断：`TBD`。

### 2.2 一条感知地平线

低位导航感知集中在连续的深色精密带中，避免分散的“机器人眼睛”。工作相机属于 A07 上部脊柱，必须通过物理遮挡、姿态和状态语义与导航感知区分。

光学/RF 性能、污损后可用性和相机隐私理解：`TBD`。

### 2.3 一个变形逻辑

桌、脚踏、座背和脊柱沿少数可追踪的运动线索收纳与展开；当前左右扶手保持固定连续，不建立侧向翻开语义。A07 是同一固定套筒、一件完整移动脊柱和同一冠梁：Ride/Café 保持低态，Follow 与 A06 共铰折叠，Focus 只把移动脊柱与冠梁升高 420 mm；不存在 `stage_2` 或 `stage_3`。A09 桌腿仍以独立三级实体表达真实级间关系，但外观收敛为 `72×70 / 60×58 / 48×46 mm` 的直壁定向 squircle 仪器套筒，并保留 `3.0 mm` 级间干隙和 `40 mm` 最内机构通道。A08 只有一套六物理发生项和一块 `210 × 500 × 10 mm` 平台：Follow/Café/Focus 主态收纳，Ride 主态展开正锁；Café/Focus 只在显式可选子态展开。脚踏支持和桌根由分件外壳包覆，但保留服务和排水边界。

静态 A07 单移动脊柱、A09 三级实体与零实体交叠：`以正式 pre/post-STEP 几何门和四态碰撞报告为准`。

动态扫掠、线束、锁止和寿命：`TBD`。

### 2.4 可读的方向与接近侧

前部低位感知地平线、脚踏展开方向、后部服务门、Café 单侧桌和 Focus 双侧边界共同说明前后与接近关系。极简不等于无方向黑箱。

2 m/5 m、5 秒无讲解识别结果：`TBD`。

### 2.5 材料真实与服务真实

承力和运动根部不得只靠黑缝假装悬浮；接触面应温和；感知窗应精确；服务门和可更换窗框必须有真实分件、开口与拆装路径。A10 的无电释放孔和拉手腔已建为减材几何，而非贴在实心门板上的图形。

A10 静态开口：`以正式 pre/post-STEP 几何门为准`。

实体操作力、防水、拆装与耐久：`TBD`。

## 3. 关键词如何转化为可检验的外观

| 关键词 | V8 的具体做法 | 不采用的做法 | 未完成验证 |
|---|---|---|---|
| 复古科幻 | 仪器式比例、低饱和矿物色、香槟色精密揭缝、少量独立状态见证、可理解的机械变形 | 怀旧装饰、铆钉堆叠、飞船舷窗、假仪表、拟人眼睛 | 实体 CMF 与用户联想：`TBD` |
| 极简 | 少数连续体量；收纳面退为周界缝；状态灯数量受限；功能件按地平线和脊柱归组 | 大面积钢琴黑、RGB 灯带、把手森林、无功能黑缝 | 5 秒读感与维护后一致性：`TBD` |
| 平滑 | 大面连续、圆角过渡、机构根部由完整外壳收束 | 用渲染法线掩盖折面、无法开模的连续封壳 | Class-A 曲率与模具实现：`TBD` |
| 高级感 | 材料职责明确、缝隙克制、状态件尺寸小且准确、服务边界有秩序 | 高光黑、伪木纹、连续发光、装饰性金属面积膨胀 | 真实色差、光泽、刮擦与老化：`TBD` |
| 神秘感 | 正确能力只在正确物理状态、身份和隐私条件下出现 | 隐藏故障、不可判断运动、静默相机、假悬浮、无解释自动动作 | 状态时序和场景测试：`TBD` |

## 4. 四态不是造型变体，而是因果链

本节描述的就是正式 4×8、共 32 张渲染中的四个主态。Café/Focus 的 A08 可选展开子态只用于单独功能验证，不得混入这 32 张图，也不得被渲染成默认外观。

### 4.1 Follow：能力被收住

第一读感应是低、完整、安静的伴随物，而不是折叠椅上盖了一只箱子。

- 同一块 4 mm 名义壁厚的 A06 空心梯形靠背折叠后直接成为 Follow 唯一上表面，不在其上叠加箱盖、罩壳或另一块伪装面；同一低态 A07 与 A06 共用铰链随行折叠，固定套筒、单件移动脊柱和冠梁均保持物理身份；
- 靠背根部由四态固定不动的左右 A04 空心根肩完成闭合；不得恢复按状态复制的 A06 根部 cheek；
- 同一 A08 为 `STOWED`；平台、两侧支持和两只护套进入内部遮蔽责任，不能通过删除展开机构来制造闭合感；车身侧手动正锁保持原位，其同一完成态拨片外罩从永久下侧服务通道可达，原始锁件不裸露；
- 下侧保持明确的开放排水/服务边界，不伪造不可维护的全封闭壳；
- A05 左右收纳面用低填充率香槟色周界揭缝取代深色矩形假屏；
- 仅机械急停可以成为必要的突出控制，状态见证不显示任务内容；
- 低位感知地平线仍说明前进方向和感知职责。

四向中心视线 B-Rep 遮蔽与内部件零交叠：`以正式 pre/post-STEP 几何门为准`。

完整人眼视域、底视、儿童视高、维修缝和实体遮蔽：`TBD`。

### 4.2 Ride：人是主体

Ride 不是把 Follow 打开成医疗座椅。座背、脚踏和扶手应围绕人建立控制边界，但外壳不能高过人或把乘员变成设备的附属物。

- 桌面继续完整收纳，避免“随时准备办公”的驾驶舱读感；
- 同一 A08 为 `DEPLOYED_LOCKED`，平台尺寸和质量与收纳姿态完全一致；
- A08 以左右独立的 `support_monocoque` 包覆两侧支持，以一件连续、开底的 `root_monocoque` 收住根部；正常视角不再读取裸杆、薄遮片或碎片化领口，排水、运动和无电释放仅从受控底部边界进入；
- 中央无电释放保持可见、可达、可解释；
- 左侧急停与控制权必须明确，不能像后贴控制器。

包覆件、A08 三处排水和 A10 开口的数字状态，以正式 pre/post-STEP 几何门为准；完整四态刚性碰撞结果以同版碰撞报告为准，不在设计依据中沿用旧轮次数字。

医疗器械误读率、乘员主体性、脚部逃生与操作可达性：`TBD`。

### 4.3 Café：只打开建立关系所需的一侧

当前 V8 CAD 定义为右侧桌面展开。该动作必须发生在驻车、桌面清空和扫掠区域安全的前提下；另一侧保持开放，使产品从“围绕我”转为“连接我们”。

- 主态 A08 为 `STOWED`，双脚自然落地；只有用户显式选择且驻车、脚部路径与前方净空确认后，才进入同一脚踏的 `DEPLOYED_LOCKED` 可选子态；
- 右桌根、桌腿和叶片形成一个连续但可服务的外观系统；
- A09 三段桌腿为直壁定向 squircle 独立实体，保持 `3.0 mm` 径向间隙、`40 mm` 内通道及原轴线/Z 硬点，不使用裸露圆杆、软盒堆叠或单一实心柱；
- 控制器退居次位，驻车和禁止移动优先被读出；
- 单侧展开不能像损坏、缺件或临时加装。

右侧三段桌腿、闭合桌腹和底部 base socket 的静态 B-Rep：`以正式 pre/post-STEP 几何门为准`。

接近侧冻结、对面人空间、杯具/设备扫掠、桌面刚度和驻车互锁：`TBD`。

### 4.4 Focus：物理隐私先于数字内容

Focus 由双桌和升起的工作脊柱建立个人工作场，但屏幕和相机不能先于身份、驻车和隐私条件醒来。

- 主态 A08 为 `STOWED`，双脚自然落地；显式展开只属于同一 A08 的可选子态，不改变 Focus 身份，也不进入正式主态图集；
- 左右桌从相同 A09 语法展开，中央接缝和两侧根部保持可解释；
- A07 只有一件完整移动脊柱；Focus 相对 Ride/Café 低态执行受控 `+420 mm`，固定套筒不动，同一冠梁随移动脊柱升高；
- Ride/Café 已存在同一 A07 低位感知地平线，不得让桅杆在 Focus 凭空出现；Follow 中该低态总成与 A06 共铰折叠；Focus 中移动脊柱在固定套筒内仍保留不少于 150 mm 的轴向捕获，实际固定/移动最短距离不得低于 5 mm；脊柱与冠梁之间必须是 16 mm 隐藏榫槽接合并保留 3 mm 径向装配间隙、2 mm 端余隙和 4 mm 外观干缝，而不是零距离面接触；
- A09 由闭合桌腹、底部 base socket 和顶部 root crown 收住桌腿根部与级间开口；base socket 对第一级保留至少 `2.4 mm` 干隙，固定 A05 内缘受控退让后对移动级保留至少 `1.5 mm`，左右桌腹之间形成 `250 mm` 中央膝部净通道；同一右侧驾驶 pod、摇杆和授权键在 Focus 仍以相同 B-Rep 和世界坐标固定外露于扶手前端，仅撤销牵引授权；
- 物理隐私遮挡与烟色光学窗是分离实体，不能用黑色贴图假装遮挡；
- 身份错误、断网、缺设备或权限不足时只恢复安全的本地部分，并说明缺失原因。

双侧 A09、单件 A07 移动脊柱、隐私窗、固定外露驾驶控制及操作手干隙的静态状态：`以正式 pre/post-STEP 几何门与 Focus raster 为准`。

桌面人体工学、离开路径、屏幕视线、相机/麦克风时序、P95 10 秒任务恢复：`TBD`。

## 5. 神秘感的实际机制

神秘感必须能被以下因果链解释并复测：

1. 产品随人到达，但在门槛、拥挤或能力边界前克制地停下；
2. 人进入或明确驻车，机械状态先被确认；
3. Café 只展开社交所需的一侧，Focus 才建立双侧工作边界并升起脊柱；
4. 物理隐私状态成立后，正确用户完成本地鉴权；
5. 正确任务才恢复；条件不足时只出现安全的部分恢复与原因说明；
6. 离开、重新移动或身份失配时，个人内容退回中性状态，采集回到更私密一侧。

V8 当前只对第 2、3 步中的部分静态几何提供 L1 证据。完整动作—灯—声—屏时序结果为 `TBD`。

## 6. 外露部件包覆责任

| 模块 | V8 外观责任 | 已完成数字证据 | 仍需实体证明 |
|---|---|---|---|
| A01 前鼻/感知地平线 | 同一前鼻壳熔接永久 front brow 与短上回边；四态正常前视、站立俯视和斜视不穿入脚舱内部，乘员侧脚部通道继续开放；不是状态盖板或用户搁板 | 单实体、前眉 2.2 mm、中央/后缘上回边 4.0 mm、与既有侧轨熔接的左右区 6.0 mm 探针、感知载体零交叠、A04 1.2 mm 干缝与脚部通道空探针，以正式几何、碰撞和 raster 报告为准 | 模具分型、排水、踢碰、积尘、全人眼视域 `TBD` |
| A03 轮组/摇臂 | 完整胎宽上冠 C-wrap、内侧下翻和前后轴平面端回吸收轮胎上半部与传动区；维修盖后设深色实体背衬，缝隙不透出背景 | 接地带元数据必须为 visible=True/half_visible=False；外侧主皮只开放 `z=0–32 mm`（`z=20` 开放/`z=55` 闭合），端回只保留局部 `z=0–70 mm` 让位（`z=55` 开放/`z=90` 闭合），并通过跨轮胎宽度与上半部的 3×3 端回覆盖网格；四轮 `±10°` 五点扫掠净距 `>=15.5 mm`；名义外宽 `750.8 mm` 且不超过 `752 mm`，以正式几何、碰撞和 raster 报告为准；正/后视不得读成竖向整块轮胎 | 泥水、热、轮端维修和全连续运动 `TBD` |
| A05 扶手/桌盒 | 收纳面为体色门和精密周界缝；左右扶手为固定连续壳体，删除侧开铰链塔、锁止见证和释放控制语义；同一右侧控制组四态固定外露，只有 Ride 允许牵引 | 禁用件清单、四态控制 B-Rep/坐标一致性、Café/Focus 操作手对桌板 `>=5 mm` 干隙和静态碰撞以正式报告为准 | 扶手强度、手指间隙、维修拆装 `TBD` |
| A06 座背/Follow 闭合场 | 只有同一 4 mm 名义壁厚空心梯形靠背折叠并形成 Follow 唯一上表面；不增加盖板；左右 A04 空心根肩四态固定，替代状态专用 A06 cheek；同一低态 A07 与 A06 共铰折叠 | A06 实体空腔/壁厚、Follow 四向视线、A04 根肩跨态同一 B-Rep、A06 净距与内部间隙以正式报告为准 | 全视域、密封、实体面差 `TBD` |
| A07 工作脊柱 | 同一固定套筒＋一件完整移动脊柱＋同一冠梁；Ride/Café 为低位感知地平线，Follow 与 A06 共铰折叠，Focus 将移动件和冠梁升高 420 mm；禁止 `stage_2/stage_3` | 单件、Focus 捕获 `>=150 mm`；移动件—冠梁为 16 mm 榫槽接合、3 mm 径向装配间隙、2 mm 端余隙、4 mm 外观干缝；跨态同一 B-Rep、受控逆变换和窗口分离以正式报告为准 | 动态刚度、线束、隐藏紧固、锁止、环境 `TBD` |
| A08 脚踏 | 一套 47 件生产意图 captured-drawer/over-centre-link occurrence；Follow/Café/Focus 主态收纳，Ride 主态展开正锁，Café/Focus 可显式选择展开；平台下托盘、左右 `support_monocoque` 与连续 `root_monocoque` 包覆机构，固定鼻壳只保留一套永久释放/运动通道 | 47 件身份、刚性 B-Rep/体积/拓扑签名跨姿态守恒；101 姿态零非预期互穿；两端锁销与中间退销；人体脚区危险由双通道 fail-closed 互锁；旧六件/`1.890987 kg` 不再有效 | 材料/EBOM/质量、泥沙、冲击、夹剪、公差、耐久、双通道电气和无电回收样机验证 `TBD` |
| A09 桌根 | Café 右叶与 Focus 双叶各自只保留一件连续收腰空心桌腹，把升降口到叶底读成同一活动物件；旧 bridge、fairing、saddle、方盒 belly 及 service fragment 全部退休 | 单实体、无微小残片；Café 对 A05 `>=1.0 mm`、对桌腿 `>=6.0 mm`；Focus 对固定 A05 `>=1.5 mm`、中央膝部净通道 `250 mm`、12 mm 桌面中缝及独立 root crown，以正式几何和 STEP 回读为准 | 动态刚度、隐藏紧固、疲劳、污物和全扫掠 `TBD` |
| A09 桌机构 | 三段直壁定向 squircle 桌腿、闭合桌腹、底部 base socket、Focus root crown 与叶片下壳共同包覆；外截面 `72×70 / 60×58 / 48×46 mm`，级间干隙 `3.0 mm`，内通道 `40 mm`，socket 对第一级 `>=2.4 mm` | Café/Focus 独立级间、轴线/Z 硬点、底座、顶部根部、静态碰撞及关键件 STEP 回读以正式报告为准 | 承载、晃动、疲劳、误用 `TBD` |
| A10 后服务区 | 齐平门、真实释放孔、拉手腔、传感/声学件各有责任 | 开口与零交叠以正式报告为准 | 防水、操作力、授权维修 `TBD` |

任何为了“更干净”而删除真实排水、释放、传感透过、散热或服务边界的改动，均视为设计回退。

## 7. CMF 纪律

当前 CAD 使用的颜色名称只表示设计角色，不是量产色板：

- `Lunar Stone`：主外壳的低饱和矿物哑光；
- `Graphite Brown / Smoked Umber`：感知和精密窗口，不承担大面积装饰；
- `Champagne`：小尺度结构揭缝、护圈和精密界面；
- `Charcoal Knit / Espresso`：人体接触与温和触感区域；
- `TPE Dark`：真实密封、踏面和防滑件；
- `Safety Red`：机械急停，不能被品牌色替代。

材料牌号、纹理编号、光泽范围、色差、涂层体系、阻燃、清洁剂、UV 和供应商样板均为 `TBD`。

## 8. 分件、缝与维修

V8 的缝必须属于以下一种责任：运动、服务、密封、材料转换或传感透过。没有责任的黑缝必须删除；需要维修却没有拆装路径的连续面必须拆分。

正式分件树、紧固策略、拆装顺序、密封截面、扭矩、防错和维修工时为 `TBD`。

## 9. 视觉设计的可证伪门

以下任一结果成立，V8 视觉方向不得冻结：

- Follow 在正常或儿童视高仍能看到被指定为隐藏的机构；
- A05 收纳面仍被多数观察者判断为熄灭屏幕；
- Ride 首要读感仍是医疗座椅，或外壳夺走乘员主体性；
- Café 被判断为缺了一半、仍可移动，或接近侧不明确；
- Focus 只被判断为 Ride 加大桌面，或相机/屏幕先于隐私状态出现；
- 复古科幻依赖装饰件而非机构与材料秩序；
- 平滑包覆导致热、RF、制动、排水、维修或制造路径失效；
- 高级感只在渲染光线下成立，实体色差、缝隙和污损后崩溃；
- 任何“神秘”行为需要隐藏遥控器、稳定云网络、预摆道具或现场工程师。

上述实体和用户测试结果目前均为 `TBD`。

## 10. 不得回退的设计约束

1. 不恢复 Follow 的堆叠板件、裸露脊柱或大面积黑色收纳面。
2. 不把 A07 退回三级行李拉杆语法，也不把 A09 的三级桌腿联合成一个假实心外观件。
3. 不用表面贴片代替 A08 排水、A10 释放和拉手的真实开口。
4. 不增加拟人眼睛、RGB 情绪灯、无功能屏幕、行李拉杆或医疗管架语言。
5. 不为任何状态复制、删减或替换 A08 物理件；不把 Café/Focus 可选展开子态冒充为四主态默认外观或混入正式 32 图。
6. 不以“极简”为由隐藏故障、运动方向、驻车、急停、隐私和接管信息。
7. 不以“概念感”为由牺牲制造、公差、服务、热、RF 或安全路径。
7. 在 Class-A、实体 CMF、人因、工程和法规证据全部完成前，发布状态保持 `TBD（BLOCKED）`。

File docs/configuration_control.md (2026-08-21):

# WorkCore configuration-control index

Status: E6R2 working design-history index. This file identifies which inputs are current and which files are historical. It does not close `G-006`: the workspace still needs an immutable source-control baseline, change authority, approvals, deviation control and a released document-management process.

## 1. Current baseline and precedence

| Layer | Current authority | Precedence rule |
|---|---|---|
| Product north star and four-state constitution | `docs/e6_product_definition_and_strategy.md` | Governs product meaning and core/option boundaries; does not override a safety restriction |
| Launch niche, ODD and scenario evidence | `docs/e6_launch_ecology_and_scenario_validation.md` | Governs the first controlled deployment wedge; narrower than the long-term E6 vision |
| Safety states and preliminary hazards | `docs/safety_state_machine.md` | A restrictive safety condition wins over a marketing or experience statement |
| Geometry and numerical design inputs | `cad/parameters.py` and current `cad/*.py` | Generated JSON/CSV is evidence of the exact code run; prose numbers are explanatory only |
| Pose identity and mass reconciliation | `docs/configuration_mass_reconciliation.md` | Any unresolved pose-dependent mass or same-name definition conflict blocks a base-SKU mass claim |
| Structural datums and interfaces | `docs/interface_control.md` plus `build/cots_interface_register.csv` | Supplier drawings and signed ICDs must eventually supersede provisional envelopes |
| Verification and production evidence | `build/production_readiness_report.json`, `build/requirements_traceability.csv`, `build/risk_register.csv`, `build/dvpr.csv` | An unexecuted plan or nominal calculation cannot be promoted to physical evidence |
| Build provenance | `build/release_manifest.json` for preserved E6-DFR3 trace inputs; `design/e6_final_exterior/step_anchored_v2/class_a_cad/controlled_source_e6_dfr4/e6_dfr4_a08_manifest.json` for the E6-DFR4-A08 primary exterior underlay | Only files whose hashes appear in the matching revision manifest belong to that generated baseline; the manifests are not interchangeable |

If two current sources disagree, the product is not allowed to choose the more convenient claim. Record an issue, apply the safer/narrower boundary, and resolve it through an approved change before release.

## 2. Revision families

| Family | Status | Permitted use |
|---|---|---|
| E6R2 / E6-DFR4-A08 | Current working exterior-source correction | Four primary exterior underlays plus Café/Focus optional-open validation states; engineering review only, not production release |
| E6R2 / E6-DFR3 | Preserved predecessor and auxiliary trace input | Historical comparison and unchanged auxiliary interfaces only; it is not the current four-state A08 publication baseline |
| E5 | Superseded product thesis; retained design history | Rationale, launch-wedge and moat history; not current geometry |
| E4 | Inherited occupied geometry, power and interface history | Input provenance only where E6 explicitly retains it; stale counts and masses are not current |
| E3/E2/E0 and v30/v37 | Historical concepts and rejected/learned alternatives | Design-history evidence only; never a release source |

All historical documents should be read as snapshots even where their original prose says “current”. The current generated report and this index take precedence for status and counts.

## 3. Evidence vocabulary

| Term | Meaning |
|---|---|
| `PASS` for an automated check | The encoded nominal rule passed for the generated model |
| `analysis_complete` | A calculation or model has been reviewed as an input; supplier, tolerance and physical evidence may remain open |
| `partial` | Some traceable input exists, but the gate's complete exit criterion is not met |
| `closed` | The controlled deliverable, objective evidence, required reviews and approval signatures all exist for the defined scope |
| `NO-GO` | The next stage is prohibited until the named prerequisites close |

The count of automated checks must always be split into solid-validity checks and semantic/analytical checks. Neither category is a substitute for tolerance analysis, physical tests, regulatory review, supplier release or manufacturing capability.

## 4. Baseline rules

1. A release candidate must reference one product revision, one CAD/code commit, one EBOM revision, one firmware/software set, one risk file, one DVP&R revision and one approved intended-use/ODD statement.
2. Part identity is pose-independent. Stowed, open, rotated or extended geometry is an occurrence transform, not a new procurement item. Options and left/right variants require explicit effectivity.
3. EBOM, MBOM, service BOM and visualization-state parts are separate structures. The current `production_bom.csv` remains a generated union/canonicalization aid until a pose-invariant EBOM reconciliation passes; it must not be used alone for purchasing, cost or unit mass.
4. `build_status.json` distinguishes generation from publication and from a product release decision. Each run generates into an empty `.build-staging/<run_id>/build`, validates the complete expected artifact set, binds it to a manifest, then publishes under an exclusive lock. Public status is `PUBLISHING` throughout the multi-file transaction; the manifest is committed immediately before the hash-bound `COMPLETE` status. A write-ahead journal and rollback copies recover an interrupted publisher, and the verifier double-reads status to reject a concurrent switch. This logical transaction does not make the product releasable: the requested stage gate must still pass.
5. Requirements, hazards, controls, design outputs, tests, reports, deviations and gates use stable IDs and explicit links. Free-text similarity is not traceability.
6. A result is not current merely because a file exists in `build/`. Package and review only artifacts listed in the matching `release_manifest.json`. Unknown or retired files are preserved to avoid destroying user data, recursively reported as unmanaged, and excluded from the release package.
7. Any change to a safety limit, structural hardpoint, supplier envelope, material, firmware, calibration, privacy behavior, ODD or public claim triggers impact analysis and regression selection.
8. A failed or conditional test remains failed/conditional. Waivers require scope, rationale, risk review, expiry, approver and affected serial/configuration range.

## 5. Current configuration-control blockers

- The Git branch has no initial immutable commit, so generated artifacts cannot yet be tied to a released source revision.
- Owners, approvers and signed evidence are missing from the development gates.
- The A08 footrest pose identity is reconciled in E6-DFR4-A08, but the remaining physical product BOM still contains other pose-state identity ambiguity and option mixing.
- E6 Core, Outdoor Pack, Dock, mirrored Café and any later care/accessibility package do not yet have independent effectivity and safety cases.
- No physical EVT, DVT or PVT report is registered; all such claims remain open.

These are release blockers, not documentation polish items.

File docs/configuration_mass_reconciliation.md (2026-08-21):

# WorkCore E6 configuration-mass reconciliation

Status: P0 configuration-control finding. These values are analytical CAD mass estimates, not measured hardware, a released EBOM or a customer specification. The former E6-DFR4 six-occurrence A08 abstraction has been superseded by the E6-DFR5 captured-drawer/over-centre-link production-intent inventory. The new geometry can close pose identity only after its executable gates pass; it reopens A08 mass and EBOM reconciliation.

## Finding

The same base product cannot gain mass merely by changing pose. The legacy E6R2 analytical configurations below do, so no single mass may be released for the base SKU from that table.

| Configuration | Legacy E6R2 analytical product mass (kg) | Delta from stowed (kg) | Interpretation |
|---|---:|---:|---|
| Stowed / restricted Follow | 114.1069 | 0.0000 | Legacy transport-model estimate only |
| Obstacle-assist | 114.6871 | 0.5802 | Telescopic handle still changes physical representation |
| Ride / seat / transfer hardware closed | 115.9876 | 1.8807 | Physical occurrences remain missing or replaced across poses |
| Café | 119.3175 | 5.2106 | Dedicated transverse linkage and deployed desk geometry are not yet represented in every pose |
| Focus / desk | 119.6816 | 5.5747 | Largest legacy core four-state inconsistency |
| Outdoor deployed | 123.1972 | 9.0903 | Mixes a true option with pose inconsistencies |

The `internal` configuration is an exploded/shell-hidden review scene and is excluded from pose-mass comparison. The generated `production_bom.csv` is a candidate union catalogue; its union mass is not a product mass.

## Known reconciliation defects

- **Superseded A08 baseline:** the old six-occurrence, `1.890987 kg` DFR4 abstraction is not a valid mass claim for the current mechanism. E6-DFR5 now carries one 47-occurrence production-intent B-Rep inventory through every pose and primary state, including fixed guides, captured rails, four links, bearings, guarded pins, endpoint locks, synchroniser, counterbalance, manual release and two-channel foot-zone hardware. Follow/Café/Focus default to `STOWED`; Ride defaults to `DEPLOYED_LOCKED`; Café/Focus may enter an explicitly requested optional `DEPLOYED_LOCKED` substate. The 47 identities and rigid transforms are executable geometry gates; material assignments, fasteners, harness, supplier parts and measured assembly mass remain open.
- The obstacle handle changes by about 0.5802kg between folded and extended representations.
- The transfer hinge/link/shrouds and joystick/authorization hardware are now instantiated in every user configuration with controlled occurrence IDs. This removed false pose deltas without claiming EBOM closure.
- Approximately 0.4600kg of travel seals still appears only in closed poses; attachment ownership and open-pose transforms remain unresolved.
- The former same-name `desk_yoke_right` collision is separated into Focus and Café linkage occurrences, so supplier STEP export can no longer silently overwrite one definition with the other. Their presence across all base poses is still unresolved and remains visible in the occurrence-set delta.
- The outdoor canopy is a legitimate option delta of approximately 7.0096kg. Creator fill lights are a separate approximately 0.2000kg option. Both require explicit option effectivity and must not appear or disappear because of pose.

## Required data model

Every physical occurrence needs a stable `physical_occurrence_id`, part number, revision, quantity and option/effectivity code. Pose changes only its transform. A replacement geometry for the same occurrence must either preserve the controlled mass/identity or advance the part revision through change control. Names and regular-expression canonicalization are not identity. The current generated report measures controlled-ID coverage and lists added/missing occurrence IDs for every base pose; incomplete coverage is itself a release failure.

The released structure must separate:

- base-SKU EBOM and measured/estimated unit mass;
- option deltas such as `OPT-CANOPY` and `OPT-CREATOR-LIGHTS`;
- pose transforms;
- validation envelopes and human/equipment keep-outs;
- MBOM consumables, service parts and shipping materials.

## Closure criteria

1. For each base-SKU pose, the set of physical occurrence IDs and quantities is identical.
2. Base-SKU pose mass spread is no more than 0.001kg after deterministic rounding.
3. Same-ID definitions match controlled mass, material, volume/bounding-box or geometry hash, supplier part and revision; any mismatch fails the build.
4. Each option is tested both installed and absent; its mass delta is pose-invariant and agrees with the option EBOM.
5. CAD estimate, released EBOM roll-up and first-article measured mass have an approved reconciliation with uncertainty and deviation disposition.
6. Only after these conditions close may product, transport, stability, power/runtime or cost reports use a frozen base-SKU mass.

For A08 specifically, E6-DFR5 requires the same 47 production-intent occurrence identities and rigid B-Reps in `STOWED` and `DEPLOYED_LOCKED`; only their allowed transforms and lock-pin engagement state may change. This closes neither a 47-line EBOM nor assembly mass: both remain P0 until every occurrence has controlled material, supplier/part revision, fasteners and harness, followed by CAD roll-up and first-article reconciliation.

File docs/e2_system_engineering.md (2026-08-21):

# WorkCore E2 系统工程结论

> 历史文件：E2 已因缺少实体人体和桌板载人运动扫掠校核而撤回，不再作为当前人机基线。当前结论见 `e3_human_centered_audit.md`。

E2 已通过当前自动化几何、包装、稳定性、结构简算和尺寸链检查，可用于样机评审、供应商询价与接口冻结。它仍不是开模或量产放行数据：材料批次、连接细节、焊接变形、疲劳、防水、电气安全和整机试验尚未闭环。

## 暂定设计边界

| 项目 | E2 暂定值 | 用途 |
|---|---:|---|
| 设计乘员 | 150 kg | 座椅与稳定性包络 |
| 设计载物 | 25 kg | 车体和稳定性包络 |
| 移动冲击系数 | 2.0 | 抽屉与桌面静力等效 |
| 单侧桌面载荷 | 30 kg | 两侧可同时满载 |
| 顶棚自动回收阈值 | 7 m/s | 正常使用控制边界 |
| 顶棚瞬态结构校核 | 20 m/s | 误操作/回收过程的短时承载，不是展开使用额定值 |
| 顶棚积水等效质量 | 15 kg | 顶棚臂保守组合载荷 |
| 排水坡度 | 3° | 防止平顶积水 |

## 当前计算结果

- 空载整机约 90 kg；额定桌面工况计入乘员、载物及两侧桌面载荷后，前后倾覆角均大于 21°，侧向大于 24°。
- 单侧桌面在 30 kg、2.0 动载系数下，立柱弯曲应力约 59 MPa、端部挠度约 1.12 mm；蜂窝板简化挠度小于 1 mm；双剪 8 mm 锁销剪应力小于 3 MPa。
- 7075-T6 顶棚臂在 20 m/s 瞬态风与 15 kg 积水组合的保守悬臂模型中，应力约 66 MPa、端部挠度约 20 mm。铰接刚度和连接疲劳仍需样机试验。
- 240 mm 行程执行器配 2:1 绕绳可获得 480 mm 桅杆输出行程；计算所需执行器力低于 2,500 N 候选件额定值。
- 250 mm 抽屉滑轨提供约 254 mm 行程；支架每侧预留 2 mm 调节，覆盖滑轨侧隙上偏差和钣金/装配尺寸链。

精确数值由 `build/engineering_report.json` 生成，几何尺寸和碰撞结果由 `build/validation.json` 生成；二者必须同时通过才能导出 E2。

## 顶棚的关键安全结论

无乘员压舱、顶棚保持展开时，20 m/s 横风的计算抗倾覆安全系数不足 1。E2 因而不声称“20 m/s 可展开使用”，而采用以下系统策略：

1. 7 m/s 触发自动回收，设置低于触发值的复位滞回；
2. 两个独立风传感通道交叉诊断，任一异常进入回收；
3. 座椅无人时使用更保守的阈值，不把乘员质量当作必要配重；
4. 失电时由弹簧/储能机构辅助回收，目标小于 8 s；
5. 20 m/s 只作为机构短时强度校核，展开状态不得作为正常工作状态。

若要获得无条件 20 m/s 展开稳定性，简化估算需要约 1.2 m 级横向支撑跨距或地面锚固。它会显著增加绊倒、部署和质量负担，不适合作为当前移动底盘的默认方案。

## 成熟件采用方向

- 抽屉：Accuride 3832-E10-DO 包络，10 英寸本体、约 10 英寸行程、12.7 mm 标称侧隙；其保持开启/关闭功能不能替代运输正锁。
- 抽屉正锁：Southco R4 两阶段旋转锁扣包络，用软闭合/缓冲承担噪声和末端冲击。
- 桅杆执行器：LINAK LA20 240 mm 行程候选，配 2:1 绕绳；最终料号须确认安装长度、行程开关、IP 等级、速度和寿命。
- 顶棚驱动：借鉴成熟盒式遮阳篷的限位、扭矩保护、可更换卷筒和排水结构，但 E2 的快速失效回收要求高于普通慢速遮阳篷电机。

## 样机放行门槛

1. 供应商 CAD 与 E2 包络对齐，并冻结孔位、连接器、维护拆装方向和线束弯曲半径。
2. 完成桌板、桅杆、顶棚臂和底盘连接的有限元或等效试验，覆盖屈服、刚度、疲劳和冲击。
3. 在空载、满载、抽屉最不利伸出、桌面单边满载和坡面工况做实物倾覆试验。
4. 完成风传感故障注入、失电回收、夹伤检测、卡滞、锁销未到位和控制器重启测试。
5. 完成淋雨、排水、盐雾/腐蚀、温升、线束磨损和至少一个完整寿命循环计划。
6. 首件测量后更新尺寸链；可调支架只吸收制造波动，不能掩盖基准错误。

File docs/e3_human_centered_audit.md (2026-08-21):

# WorkCore E3 载人产品全面审视

## 状态声明

E2 撤回作为人机合格基线。它把 150 kg 乘员简化为重心点，只验证了稳定性，没有验证人体占据空间、桌板运动路径、腿脚、进出和夹伤。E3 改为“人体实体 → 动作扫掠 → 产品几何 → 外观/收纳”的验证顺序。

E3 当前可用于人机布局样机和下一轮机构评审，仍不是载人行驶或量产放行数据。

## E3 已改正的几何问题

| 项目 | E2/v37 问题 | E3 处理 | 当前自动校核 |
|---|---|---|---|
| 桌板位置 | 后缘 X=72 mm，侵入躯干 | 后缘移到 X=-190 mm | 躯干/骨盆净距 100 mm，要求 ≥75 mm |
| 桌板运动 | 未建人体扫掠 | 先在扶手护罩内前移，再在人体前方展开 | 平移扫掠净距 42 mm；前方展开净距 100 mm |
| 大腿空间 | 只查桌板与盖板 | 加入左右大腿实体 | 桌板下净距 115.5 mm，要求 ≥75 mm |
| 中心拼缝 | 以 0 mm 为目标，形成夹指缝 | 改为名义 12 mm 开口并倒圆 | 实际约 12 mm，要求 10～20 mm |
| 座椅/扶手 | 550 mm 高座面、扶手内距偏紧 | 座面约 520 mm；座宽 590 mm；扶手内距 620 mm | 骨盆/躯干与扶手无侵入；前向离开净宽 620 mm |
| 腿脚 | 没有乘员脚踏和足部路径 | 增加 500 mm 宽、210 mm 深的手动脚踏及前足井；Ride 默认展开，Café/Focus 默认收纳并保留脚落地路径，也允许显式展开 | 小腿、脚与壳体/前轮无碰撞；同一 A08 组件的收纳—展开扫掠无干涉 |
| 头部/横梁 | 未检查头部 | 横梁和桅杆后移 | 头部净距约 75 mm |
| 收纳尺寸 | 为紧凑包络压缩人机空间 | 按用户指示降为记录项 | 不作为 E3 人机验收门槛 |

当前 `validation.json` 包含 364 项检查，`engineering_report.json` 包含 31 项检查，均无失败。这里的“通过”仅代表当前参数化简化模型通过自定义门槛，不代表通过法规或实物试验。

## 仍然存在的 P0 问题

以下问题未解决前，禁止称为可载人行驶产品：

1. **载人动态稳定性**：需要制动、加速、转弯、坡面、单轮越障、桌板偏载、抽屉误开和脚踏受撞工况；当前只有准静态重心/倾覆角模型。
2. **乘员保持与紧急停止**：未定义安全带、骨盆定位、扶手承载、急停位置、失控制动和控制器失联后的安全状态。
3. **上下车与故障逃生**：正常前向离开已有几何通道，但桌板、脚踏或盖板卡滞时的机械快拆尚未设计；必须能无电释放。
4. **脚踏强度和防卷入**：脚踏、铰链、闩锁、前缘防撞、轮胎卷入防护和受撞后脱离方式未完成。
5. **桌板真实机构**：E3 已定义安全运动顺序和扫掠包络，但三折叶片、前移滑架、锁销、护罩和单手释放还只是接口几何，未完成疲劳/夹伤样机。
6. **制动与驱动**：四轮毂的驻车制动、断电制动、转向策略、轮胎侧向擦地和冗余未定义。
7. **电池/热/火灾**：电池位于乘员下方，尚无电芯失效传播、排气方向、隔热、防水、碰撞和紧急断电验证。
8. **功能安全**：座椅占用、脚踏锁止、桌板锁止、抽屉锁止、顶棚回收和驱动许可之间尚未建立经风险等级确认的硬件安全链。

ISO 7176-1 提供轮椅静态稳定性试验方法；ISO 7176-8 覆盖静载、冲击和疲劳；ISO 7176-14 覆盖电动轮椅/代步车的动力与控制系统。WorkCore 的最终法规分类尚未确定，但其载人移动风险与这些试验域高度相似，至少应作为设计输入而不是只做普通家具校核：[ISO 7176-1](https://www.iso.org/standard/56817.html)、[ISO 7176-8](https://www.iso.org/standard/64902.html)、[ISO 7176-14](https://www.iso.org/standard/72408.html)。

## P1 人机与使用体验问题

- **目标人群未冻结**：当前采用保守穿衣人体包络，但必须明确性别比例、身高/体重范围、行动能力、冬装、是否允许残障用户及使用时长。
- **座椅不可调**：需要至少验证座深、腰托、靠背角、座垫压力、扶手高度和长时间热湿舒适；150 kg 强度额定不能替代体型适配。
- **显示与输入缺失**：屏幕尺寸、视距、视角、键盘/鼠标主操作区和阳光可读性没有实体。频繁操作物不能放到桌面远端。
- **手臂动作**：桌板最终位置已避开躯干，但展开手柄、解锁力、左右手可达性和单侧使用尚未做 5th～95th 百分位人在环测试。
- **侧向抽屉**：乘员坐着时侧后方抽屉不适合频繁访问，并诱发扭转；常用物应进入前方或扶手触达区。
- **顶棚**：头部和横梁已分离，但雨水排放、侧风、夹手、织物下垂、收回时滴水和紧急回收噪声仍会影响乘员。
- **乘坐振动与噪声**：轮毂、电机、风扇和抽屉间隙会把振动直接传到座椅和触面，尚无频谱/声压目标。

OSHA 明确要求工作面下有足够腿部空间、扶手不干扰工作面、脚应得到地面或脚踏支撑，并通过可调节性适配不同用户；这正是 E2 漏掉的验证层。[OSHA 椅子](https://www.osha.gov/etools/computer-workstations/components/chairs)、[OSHA 工作空间](https://www.osha.gov/etools/computer-workstations/components/work-space)、[OSHA 评估清单](https://www.osha.gov/etools/computer-workstations/checklists/evaluation)。

## 产品定义中的矛盾

1. “动力件封顶 8 个”后面的清单实际为 9 个：四轮毂 + 风扇 + 抽屉电磁闩 + 脚踏闩 + 盖板闩 + 顶棚电机。E3 建议抽屉改用机械正锁，动力件回到 8 个。
2. “功能让位于形”不能用于载人安全。E3 改为：生命安全/人体包络 > 可操作性 > 机构与维护 > 外观连续性。
3. 180 mm 车轮在没有主动攀爬机构时，不应声称 90～180 mm 单级越障。≤40 mm 也必须经过接近角、扭矩、打滑和倾覆试验；当前对外能力应写为“未验证”。
4. “收起后 790 x 660 x 700 mm”已按用户最新指示降级，不再约束人体空间；实际收纳尺寸如实记录即可。

## 下一轮物理样机应回答的问题

- 5th percentile 女性与 95th percentile 男性、厚衣物和至少两种体重体型是否都能坐入、操作并在 10 秒内离开？
- 双侧桌板能否分别在 3 秒内单手展开，且任何时刻不要求身体后仰、收腹或抬肘躲机构？
- 桌板偏载、用户扶撑起身、急刹和单轮越障时，锁销、扶手和底盘是否仍有足够强度与稳定性？
- 无电、控制器损坏、桌板卡滞、脚踏卡滞时，乘员是否能独立机械释放？
- 连续 2 小时使用后的座压、腰背、前臂接触、腿部空间、热湿和噪声是否可接受？

NASA 的人因标准要求以目标人群数据、任务分析、人体动作范围和反复人在环测试成熟设计。E3 的 CAD 包络是进入实物验证的起点，不是替代实物验证的终点。[NASA 人因系统工程](https://www.nasa.gov/reference/3-0-systems-engineering-processes-vol-2/)

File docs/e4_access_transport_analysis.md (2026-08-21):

# WorkCore E4 通行、商店、电梯与后备箱可行性

## 计算包络

| 状态 | 长×宽×高 | 质量/说明 |
|---|---:|---|
| 收纳 | 约 867×740×690 mm | 空载约 121.1 kg；不得徒手装车 |
| 载人行驶 | 约 1095×740×1183 mm | 含展开脚踏和操控/急停接口，不含人体头部包络高度 |
| 原地转向 | 直径约 1371 mm | 以真实零件包络绕轴距中点计算，不用外接矩形虚增 |

最终数字以 `build/validation.json`、`build/engineering_report.json` 和 `build/mobility_report.json` 为准；制造公差、软包鼓包和线缆不应消耗通行余量。

## 门与商店

依据 [`GB 55019-2021 建筑与市政工程无障碍通用规范`](https://snamr.shaanxi.gov.cn/sy/ztzl/sbgxhxfpyjhx/bzcx/gjbz/202410/P020250320617603414157.pdf)，新建无障碍手动门净宽不应小于 900 mm，自动门不应小于 1000 mm；既有建筑改造可出现 800 mm 净宽。

| 净宽 | E4 总余量 | 判断 |
|---:|---:|---|
| 800 mm | 约 56 mm | 可通过，但每侧约 28 mm；只允许 0.20 m/s 精准模式，必须有边缘测距/防夹 |
| 900 mm | 约 156 mm | 每侧约 78 mm，可作为正常低速通行基线 |
| 1000 mm | 约 256 mm | 舒适通行，可容纳一定门框/软包误差 |
| 1200 mm 走道 | 约 456 mm | 直行可行；会车与货架端转弯仍需局部放大空间 |

商店不能只看走道名义宽度；陈列篮、广告牌、门禁柱、排队人群和临时货物都会缩小实际净宽。控制器应把左右前角测距和低矮障碍检测纳入 800 mm 精准通行模式。

## 电梯

规范中的最小无障碍轿厢为 1100×1400 mm；E4 载人包络约740×1095 mm可沿轿厢深度直进、同向退出。900 mm门余量约160 mm；800 mm旧梯门仅属精准通过。

1371 mm 的原地转向直径不能装进 1100 mm 轿厢宽度，因此不得承诺在最小轿厢内原地转 90° 或 180°。正确体验是：

1. 在约 1500 mm 的电梯厅转正；
2. 低速直进轿厢；
3. 驻车并保持桌板/顶棚收纳；
4. 到站后同方向直出；必要时使用后视摄像头和自动居中辅助。

1500 mm 门厅对 1371 mm 转向直径只有约 129 mm 总直径余量，必须清除垃圾桶、候梯人员和门套突出物；这不是高速掉头空间。

## 后备箱

后备箱没有统一通用开口。E4 使用四个内部参考模板做早期筛选，不能替代实车测量：

| 参考模板 | 结果 | 原因 |
|---|---|---|
| 轿车 1000×550 开口、900 深 | 不可行 | 689 mm 收纳高度超过开口 |
| 紧凑 SUV 1050×700、850 深 | 不作为量产适配 | 高度仅约11 mm余量且深度短约17 mm |
| 中型 SUV 1100×780、1000 深 | 几何可行 | 高度约91 mm、深度约133 mm余量；仍需实车轮拱和后排角度确认 |
| MPV 1150×900、1100 深 | 几何可行 | 余量较充分；仍需升降与系固系统 |

空载约121.1 kg，不能让用户抬进后备箱。当前计算要求车载升降平台至少970×850 mm、额定不低于160 kg；平台应直接作用于四个底盘系固点，不能把车轮制动器当运输捆绑。若目标必须覆盖紧凑SUV，正确方向是可拆卸动力底盘/座舱模块或专用拖架，而不是继续压缩乘员空间。

收纳目标900×760×700 mm现在分别保留约33、19.9和10.3 mm名义生产余量；构建已将20/10/10 mm最低余量写成自动检查。高度余量仍偏紧，DVT必须叠加轮胎、软包、线束、地面和装配极限实测。

## 现场准入表

每个用户住所、商店或车辆在交付前至少测量：最窄门净宽、门槛高度和坡度、电梯门实际全开宽度、轿厢净尺寸、厅内回转净空、坡道横坡、车辆开口最窄宽高、轮拱间距、装载深度、门槛高度和升降设备额定值。任一尺寸小于模型要求加制造/操作余量时，不作兼容承诺。

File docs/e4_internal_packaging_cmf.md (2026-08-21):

# WorkCore E4 内部仓位、壳体与最终材料评估

## 结论

当前模型已经包含完整外壳实体和每个零件的材料/工艺类别，但还不是最终 CMF 或开模数据。可以用于内部包装、碰撞、质量和供应商接口评审；不能据此直接开注塑模，因为拔模、分型线、卡扣、螺柱、密封槽、表面纹理和涂层厚度尚未全部工程化。

本轮修正了两个真实问题：原上层抽屉只能可靠覆盖 14 英寸设备，且计算核心与配电盒存在约 579,040 mm³ 包络重叠。现在模块间无相交，最小服务净距 10 mm。

## 笔记本设备仓

左右上层抽屉现在均定义为笔记本仓：

| 项目 | 当前值 |
|---|---:|
| 抽屉托盘包络 | 440×290×88 mm；面板高 80 mm |
| 验证用笔记本包络 | 365×255×28 mm |
| 设备到托盘最近净距 | 11.0 mm |
| 设备到前面板净距 | 10.5 mm |
| 滑轨长度/行程 | 300/305 mm |
| 内衬 | 410×270×8 mm 可替换缓冲泡棉 |

该包络覆盖绝大多数 14、15.6 和 16 英寸轻薄本/常规本；不承诺覆盖 17 英寸、超厚游戏本或带永久外壳的设备。量产适配表必须使用实际机型的长、宽、厚和电源接头突出量。

设备仓定位为关机/睡眠状态运输仓，而不是封闭高负载运行仓。若需要在仓内充电，必须增加独立温度传感、阻燃内衬、受控 USB-C 功率、冷凝/泄压膜和超温断电；在这些验证完成前禁止笔记本闭仓高负载运行。

下层设备仓现为 260×240×88 mm 托盘，X/Z 基准为 −100/260 mm，左右滑轨行程 254 mm。自动检查将上下层仓的托盘、面板、滑轨和锁扣分别扫过全行程，并叠加轮系摇臂 −10°、−5°、0°、+5°、+10°；当前最差名义间隙为 17.676 mm。该值仍须用最大实体轮胎、低压鼓包和装配偏差复核。

## 内部模块布局

| 模块 | 接口包络 | 位置与维护评价 |
|---|---:|---|
| 16S 30 Ah LFP 电池 | 360×440×90 mm，20.5 kg接口包络 | 底盘最低层；置于 380×460×110 mm 结构安全盒内；后向泄压；需从底部专用工装拆卸 |
| 驱动/IMU 控制器 | 160×140×28 mm | 电池上方留 21 mm；独立低压线束，不与泄压路径共用空间 |
| 计算核心 | 94×140×130 mm | 后部竖向服务区；与数据仓分离，便于整盒更换 |
| 加密数据仓 | 94×140×55 mm | 可拆卸、可封签；与计算核心 10 mm、与配电盒 15 mm 净距 |
| 通信模块 | 94×180×140 mm | 与计算核心横向隔开 40 mm；天线馈线需走独立弱电通道 |
| 配电盒 | 94×440×40 mm，3.8 kg接口包络 | 后上部横向布置；分区容纳主熔断、维修断电、预充/双接触器、DC/DC、USB-C和网络；不再侵入计算核心 |
| 停车态逆变器 | 180×120×55 mm，1.8 kg | 中央下层；只在驻车并满足热条件时使能；不占用左右笔记本仓 |
| 安全备份电池 | 100×100×45 mm，1.2 kg | 24 V/60 Wh独立安全轨；只供安全控制、最低通信和应急照明 |
| 双温度通道 | 28×28×10 mm×2 | 电池盒前后分区，不能只依赖 BMS 单点温度 |

本轮已建立线束分区、主干截面、桅杆拖链和热管理包络，但仍需补齐：连接器精确料号/针脚、保险曲线、束内降额、风道压损、EMC接地、IP密封、排水最低点和维修工具空间。当前几何净距不是所有连接器通用余量。

主操控器、机械急停、后部充电、可上锁维修断电、双动作手动制动释放和声光状态接口已加入模型。它们仍是受控包络，最终零件、操作力、可达性、防水和诊断必须在EVT/DVT验证。

v37 功能基线现已重新实体化：右扶手为可拆摇杆/授权键控制舱，左扶手为124×50 mm小屏和15 W Qi2托盘，后甲板为双管伸缩越障拉杆。小屏、线圈、FOD/温度/在位模块、拉杆套管/锁止/横把均进入BOM；外观曲面、玻璃盖板丝印、Qi表面材料、排水和拉杆槽密封仍未冻结。

## 壳体和表面材料成熟度

| 区域 | 当前材料定义 | 建议最终表面 | 当前成熟度 |
|---|---|---|---|
| 下车体/电池盒/防火隔板 | 5052-H32 铝板 | 60～80 μm 细纹粉末喷涂，内部绝缘耐火涂层 | 材料和壁厚已有；焊缝、密封和排水待详细设计 |
| 上甲板、扶手、后背、桅杆和运动护罩 | PC-ABS | UV 稳定、哑光细纹、耐清洁剂；阻燃等级按最终法规确认 | 外形壳体已有；拔模、卡扣、螺柱、分件待完成 |
| 桌板 | 铝蜂窝夹芯 | 耐磨低反光饰面、圆角封边 | 结构包络已有；封边和液体耐受待试验 |
| 座垫/靠背 | 泡棉与软包包络 | 可拆洗、低 VOC、防泼水、接触面透湿 | 仅有软包包络；泡棉分层和缝制纸样未冻结 |
| 桌腿、脚踏连杆 | 铝结构 + TPE 护套 | 黑色可更换波纹/卡扣护套 | 护套实体已加入；寿命和夹伤探棒待验证 |
| 摇臂 | 50×10 mm 7075 深板包络 + PC-ABS 侧裙 | 与下车体同色，轮胎侧保留维护间隙 | 已消除原 36 mm 方管占用轮胎的错误包络；孔边、屈曲、疲劳、泥水和碎石冲击待验证 |

## 安全带与侧开扶手

安全带没有从安全架构中删除。它已改成座垫缝内卷收，常态外观不显示横跨乘员的带体；额定越障、坡道和照护模式仍应提示使用。若最终坚持完全取消约束，必须同步降低速度、制动和越障能力，并重新完成乘员抛出风险评估。

侧开扶手从标准年轻用户版本中取消外露铰轴，改为老年照护选装包。标准状态是固定、封闭扶手；选装移乘状态使用 PC-ABS 铰轴罩和连杆罩，不能裸露金属杆和夹点。

## 外露结构处理

- 桌板升降管：增加可替换 TPE 柱套。
- 脚踏支撑管：增加外套式护罩。
- 左右摇臂：轮间区域增加 PC-ABS 侧裙。
- 桅杆执行器：增加 PC-ABS 外壳。
- 靠背结构：增加后壳，承力框架不再作为最终接触表面。
- 移乘铰轴：仅存在于照护选装状态，并由铰轴罩/连杆罩封闭。

所有护罩还必须通过夹伤探棒、运动扫掠、泥水、碎石、线缆磨损和免工具拆装验证；当前实体证明“能够遮挡且有包装空间”，不等同于护罩已经可开模。

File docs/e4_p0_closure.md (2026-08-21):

# WorkCore E4 P0 闭环矩阵

## 状态定义

- **设计闭环**：危险已落实到参数、实体几何、硬件架构和自动检查，允许制造工程样机。
- **物理放行**：完成规定样机、人在环、环境和故障注入试验后，才允许载人或量产。

E4 每次构建必须让几何、工程、通行性和电气热管理自动检查全部通过；具体数量以最新 `build/production_readiness_report.json` 为准。检查数量会随规则增加而变化，不能把“既有规则 0 失败”误写成“模型 0 风险”。生产准备门、法规证据和物理试验与自动检查分开统计；任何一项物理放行试验缺失，都不得对外宣称量产或载人认证完成。

| P0 | E4 设计闭环 | 当前计算/几何证据 | 物理放行门槛 |
|---|---|---|---|
| 桌板侵入乘员 | 后缘 X=-190；护罩内先前移、人体前方再展开 | 核心净距 100 mm；平移扫掠 42 mm；展开扫掠 100 mm；大腿净距 120.5 mm | 5F～95M、冬装、误操作假人扫掠；左右各 20,000 次循环 |
| 桌板展开后盖板不能关 | 最终状态盖板位于 Z=676～680；前移滑架在盖下 | 面板到盖板 37.3 mm；滑架到盖板 10 mm；无相交 | 双通道关盖/锁止检测；盖未闭时机械阻止展开；污染与公差极限试验 |
| 下层设备仓与轮系穿模 | 下层仓由 320 mm 缩至 260 mm，X 基准移至两轴中点 −100 mm，Z 基准升至 260 mm；摇臂改为 50×10 mm 深板包络 | 左右仓全行程 × 摇臂 −10°～+10° 共 100 组合；0 相交；最差名义间隙 17.676 mm，门槛 15 mm | 轮胎最大外径/跳动、低压鼓包、摇臂极限、侧向载荷和仓体偏载下复测；泥沙结冰条件另测 |
| 四轮差速原地转向 | 250 mm 轮、560 mm 轴距、四个 70 N·m 峰值轮毂；0.30 m/s、2 s 扭矩爬升 | 载人转弯直径约 1371 mm；干地峰值偏航安全系数约 1.34 | 满载高摩擦地面、湿地、低压胎、老化胎温升/电流/侧滑；不得连续原地磨胎 |
| 刚性四轮悬空与冲击 | 左右中央铰接摇臂，机械限位 ±10°；实体包络为 50 mm 高、10 mm 侧向厚的 7075 深板 | 对角轮差约 97 mm；极限动态弯曲应力计算约 187.6 MPa，门槛 240 MPa | 单轮/对角障碍、坡折、侧坡、轮载均衡、线束弯折、屈曲、连接孔承压和摇臂疲劳 |
| 过度宣传越障 | 额定 50 mm；60 mm 仅作条件样机上限 | 50 mm：扭矩 SF≈1.82、附着 SF≈1.92、脚踏余隙 30 mm；计算上限 60 mm | 150 kg 乘员+25 kg 载荷，干燥高附着、垂直正向、≤0.10 m/s；至少 1,000 次；湿滑和斜向另测 |
| 急刹/溜车/失电 | 四轮 30 N·m 弹簧施加断电制动；最高速度 1.67 m/s | 0.25 g 制动需求约 22 N·m/轮；10°驻坡需求约 15.3 N·m/轮；含 150 ms 控制延迟停车约 0.82 m | 满载冷/热/湿制动、单路制动故障、10°驻坡 30 min、断电与控制器重启 |
| 乘员被甩出 | 骨盆带、双结构锚点、单手可释锁扣 | 实体接口已建；急刹前倾覆 SF≈2.99 | 锚点静载、冲击、误扣、单手释放和不同体型定位；禁止把桌板当约束 |
| 老人无法侧向移乘 | 右上扶手及桌板盒后外摆；固定底座低于座面 | 470×420×330 mm 侧向净空无侵入；底座顶面 Z=498 < 座面 Z=500 | 床/沙发/轮椅高度差、移乘板、照护员操作、单手/低握力、无电释放和夹点试验 |
| 脚部悬空/卷入 | 540 mm 脚踏、70～130 mm 高度调节、前足井、前缘缓冲 | 小腿/脚与壳体及前轮无相交；脚踏底部离地 80 mm | 2×动态载荷、前缘撞击、锁止污染、鞋带/衣物卷入探棒及受撞脱离 |
| v37功能基线丢失 | 恢复后置双管越障拉杆、右扶手摇杆/授权键、左扶手小屏与Qi2托盘 | 拉杆操作高度约1350 mm、助攀姿态8°；配件进入CAD/BOM；Qi含FOD/温度/在位包络 | 拉杆20,000次、双锁/误用/坡面；小屏可读性；Qi温升/异物/湿污和盖板互锁 |
| 电池热失控朝向乘员 | 结构安全盒、后向泄压管、乘员下方连续防火隔板、双温度通道 | 实体隔离接口进入 BOM 和 STEP | 单电芯传播、气体/火焰路径、IP、防撞、浸水、过充、主接触器粘连与紧急断电 |
| 机构未知仍驱动 | 锁位双通道 + 硬件驱动许可链；任何未知进入 FAULT_SAFE | 状态机定义驱动、桌板、移乘、脚踏和顶棚互锁 | 断线/短路/粘连/重启/通信超时故障注入；安全等级由最终风险评估决定 |
| 车内人工搬运伤害 | 整机不允许徒手抬入后备箱 | 当前质量以工程报告为准，已超过普通人工搬运范围 | 车辆升降平台或滚入系统额定 ≥150 kg；四点底盘系固；实车开口和轴荷确认 |

## 禁止对外宣称

在物理放行完成前，禁止使用“可量产载人”“60 mm 全路况越障”“任何电梯均可进入”“适配所有 SUV 后备箱”“老人无需照护即可使用”等表述。

允许的工程表述是：E4 已完成参数化设计闭环，可制造 P0 工程样机；50 mm 是待样机确认的额定目标，60 mm 是严格条件下的计算/试验上限。

## 样机顺序

1. 无人配重底盘：制动、失电、转向、轮载和越障。
2. 150 kg 假人：单轮/对角障碍、急刹、侧坡和机构误动作。
3. 5F～95M 人在环静态样机：桌板、移乘、逃生、视野和操作力。
4. 受控低速载人：先照护模式，再创作模式；逐步开放速度和障碍高度。
5. 环境与耐久：水、尘、温度、盐雾、线束弯折、20,000 次机构循环和整车振动。

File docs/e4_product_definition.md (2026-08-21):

# WorkCore E4 产品定义：东亚载人移动工作核心

> E5 产品定盘说明：本文件的人体、安全和几何边界继续有效；首发市场与功能范围由 `e5_product_thesis_and_production_strategy.md` 接管。原“90% 年轻极客 + 10% 老人”不再作为首发市场比例，老人照护声明需进入独立验证的后续 SKU。

## 目标与优先级

E4 的人体工程基线冻结为东亚成年人。E5 首发聚焦受控环境中的高价值知识工作者，并优先覆盖存在轻中度移动限制、疲劳或伤后恢复需求的人；居家老人仍作为保守安全、低握力、逃生和移乘验证样本，但不构成首发照护声明。任何后续照护 SKU 都不得降低生命安全、逃生和移乘要求。

设计优先级固定为：乘员生命安全与人体包络 > 独立进出/无电逃生 > 驾驶与制动 > 工作效率 > 维护与制造 > 收纳和造型。收纳尺寸只能在不破坏前五项时优化。

人体数据以中国现行 [`GB/T 10000-2023 中国成年人人体尺寸`](https://openstd.samr.gov.cn/bzgk/std/newGbInfo?hcno=B19DCCA575D9406856ABF87A511EE11F) 为主要输入；老年用户还需按 61～70 岁及 70 岁以上人群分别做实物试坐。当前 CAD 使用的是带冬装余量的保守包络，不把单一百分位或单一性别当成“平均人”。

## E4 冻结的人机参数

| 项目 | E4 名义值 | 设计意图 |
|---|---:|---|
| 座面高度 | 500 mm | 配合专用脚踏；兼顾工作坐姿和侧向移乘 |
| 有效座深 | 420 mm | 避免短腿用户腘窝受压，同时保留大腿支撑 |
| 座宽 | 590 mm | 覆盖厚衣和体型变化 |
| 扶手内净宽 | 620 mm | 躯干包络 560 mm，两侧总余量 60 mm |
| 扶手面高于座面 | 180 mm | 接近低位舒适扶手，避免耸肩 |
| 桌面高度 | 705 mm | 高于座面 205 mm；适合键鼠/轻办公，不作为扶起把手 |
| 桌板后缘 | X=-190 mm | 与躯干/骨盆保持 100 mm 实体净距 |
| 脚踏上表面 | 100 mm，允许 70～130 mm 调节 | 短腿和长腿用户均由脚踏承重，不悬腿 |
| 乘员设计质量 | 150 kg | 强度/稳定性输入，不等同于人体尺寸百分位 |
| 额定最高速度 | 1.67 m/s | 约 6 km/h；老人模式另行降速 |

长期使用还必须加入可调腰托、座垫压力分布、15～20 mm 座面隔振层和左右手等价操作。E4 几何没有把“坐得下”误写成“坐得舒服两小时”。

## 两套交互配置

- **创作模式**：允许最高 1.67 m/s，桌板提供双侧独立展开、键鼠主操作区和供电接口；桌板展开时驱动硬件禁用。
- **照护模式**：建议最高 0.8 m/s、加速度不高于 0.05 g、默认禁用原地急转，采用大字号高对比界面、持续按压式驱动和有线照护员手柄。

扶手恢复 v37 非对称功能基线：右侧为可拆控制摇杆和双动作授权键，左侧为朝坐姿视线倾斜的小屏及 15 W Qi2 托盘。Qi 区必须有异物检测、线圈温度和手机在位检测；手机在位时拒绝开启左侧服务盖板。运输态将右侧控制舱收入设备仓，以保持 700 mm 收纳高度目标。

两种模式共享断电制动、机械急停、骨盆带、脚踏锁、桌板锁、扶手移乘锁和电池安全链。软件配置不能旁路硬件安全条件。

## 关键构型

1. **就坐/行驶**：脚踏展开并双锁；桌板收纳；两侧上扶手机械锁闭；骨盆带可单手释放。
2. **桌板**：折叠束在扶手内部先前移，扶手盖板重新闭合并双确认，随后桌板只在人体前方展开。最终桌板状态的盖板是关闭的。
3. **右侧移乘**：驻车且断驱动后，右上扶手连同桌板收纳盒向后外摆 100°；固定底座低于座面。470×420×330 mm 侧向移乘净空无几何侵入。
4. **转向/越障**：四个固定轮毂电机按左右差速控制；左右各一条中央铰接摇臂保持四轮接地。原地转向只允许低速峰值工况。
5. **故障逃生**：桌板、脚踏、上扶手和骨盆带必须能在无电时机械释放；无线连接和主控制器均不是逃生依赖项。
6. **越障拉杆**：保留 v37 后置双管伸缩拉杆，收纳时横把平嵌后甲板，展开后操作高度约 1350 mm。只允许在无人、脚踏收纳、靠背/桅杆折叠、桌板/抽屉锁止和四轮制动可用时伸出；8° 后倾助攀是人工低速处理姿态，不属于载人 50 mm 额定越障能力。

## 标准与验证边界

E4 计算和 CAD 用于冻结样机输入，不是型式试验。静态/动态稳定、最高速度、控制和制动、静载冲击疲劳、电池与充电器、脚轮耐久及姿态变化，应分别映射到现行 [`GB/T 18029` 系列](https://openstd.samr.gov.cn/bzgk/std/std_list?p.p1=0&p.p2=GB%2FT+18029&p.p90=circulation_date&p.p91=desc)的适用试验域。最终法规分类、目标市场和认证路径必须由合格机构确认。

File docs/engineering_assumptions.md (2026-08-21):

# WorkCore E0 engineering assumptions and gates

## Status vocabulary

- **Fixed**: inherited directly from the v30 concept or selected as the E0 datum.
- **Provisional**: adequate for packaging CAD but must be confirmed before detail design.
- **Gate**: missing information that prevents production release.

## Fixed E0 geometry

| Item | Value |
|---|---:|
| Overall body envelope | 810 x 680 mm |
| Wheel diameter / tread width | 180 / 58 mm |
| Wheel centre height | 90 mm |
| Main canopy projection | 800 mm |
| Main canopy width | 380 mm |
| Deployed canopy width | 620 mm |
| Canopy roller tube OD | 40 mm |
| Canopy deployed mast stroke | 480 mm |

The lower structural enclosure is narrowed to 552 mm in E0.1.  This preserves at
least 8 mm tyre-to-structure running clearance while the cosmetic upper deck retains
the 680 mm visual envelope.

## Provisional manufacturing architecture

| Subsystem | E0 material/process | Notes |
|---|---|---|
| Chassis | 6061-T6 rectangular tube, welded then finish-machined | 40 x 40 x 3 mm members |
| Lower body | 5052-H32 folded/welded aluminium enclosure | Packaging solid only in E0 |
| Upper deck/body panels | PC-ABS or thermoformed composite panels | Split lines and draft not designed |
| Seat/back structure | 6061-T6 frame with replaceable upholstery carrier | Foam and textile represented as envelopes |
| Mast | 6061-T6 nested rectangular extrusion | Bearing pads and anti-rotation key not designed |
| Canopy arms/front rail | 6061-T6 extrusion | Wind load and joint pins are gates |
| Canopy fabric | PU-coated polyester, 0.8 mm CAD thickness | Pattern, seams and prestress are gates |
| Wheel hubs/axles | 6061-T6 hub, stainless axle | Bearings and drive torque are gates |

## E0 clearance rules

- 0.5 mm per side: CNC-machined static fit.
- 1.0 mm per side: aligned telescoping members with bearing pads.
- 1.5 mm per side: formed or moulded adjacent panels.
- 3.0 mm minimum: exposed moving mechanism under controlled alignment.
- 8.0 mm minimum: wheel-to-fixed-body running clearance.
- 12.0 mm minimum: pinch-zone design target where fingers can enter; guarding is still required.

## Human-factors verification baseline

E0 uses an adjustable-user target rather than treating the v30 visual dimensions as sacred.
The current CAD moves the compressed seat top to 550 mm, uses a 430 mm usable seat
depth and 560 mm seat width, and raises the armrest top to 735 mm.  These values are
checked automatically against the published OSHA workstation ranges.  The fixed high
seat remains near the top of the OSHA range because the 180 mm mobility wheels package
under the body; a stable footrest is therefore a required system component, not an
optional accessory.

- Seat top target: 381-559 mm (15-22 in).
- Usable seat depth target: 381-432 mm (15-17 in).
- Seat width: at least 457 mm (18 in).
- Armrest top above compressed seat: 178-267 mm (7-10.5 in).
- Seated keyboard/work surface adjustment target: 559-762 mm (22-30 in).
- User controls: one-hand operation without tight grasp/pinch/twist; design operating
  force no more than 22.2 N (5 lbf) where accessibility is in scope.
- Leg clearance target near the user: at least 520 mm wide and 440 mm deep at knee
  level; table packaging must demonstrate this in E1.

Sources: [OSHA workstation purchasing guide](https://www.osha.gov/etools/computer-workstations/checklists/purchasing-guide),
[OSHA workspace clearance guidance](https://www.osha.gov/etools/computer-workstations/components/work-space),
and [U.S. Access Board operable-parts guidance](https://www.access-board.gov/ada/guides/chapter-3-operable-parts/).

## Tolerance and rework strategy

1. Use the chassis top plane as datum A, the longitudinal centre plane as datum B, and
   the rear crossmember machined face as datum C.  Modules locate to A|B|C; cosmetic
   skins never establish mechanism position.
2. Put slots in replaceable brackets, not in the welded frame.  After welding, machine
   the wheel/hinge/mast interfaces in one setup or use a dowelled fixture.
3. Use two round pins plus one relieved/diamond pin pattern for removable modules so
   location is deterministic without over-constraint.
4. Tolerance critical gaps from process capability: CNC interfaces ±0.10 mm, laser-cut
   features ±0.20 mm, formed panel interface features ±0.50 mm provisional.  Do not
   combine worst-case cosmetic tolerances into kinematic loops.
5. Use vendor CAD envelopes and hole patterns for purchased slides, hinges, actuators,
   bearings and latches.  Never dimension production brackets from a rendered mesh.
6. Add go/no-go gauges for mast tube fit, wheel alignment, drawer parallelism and latch
   engagement.  Every adjustment must have a measurable nominal and bounded range.
7. Freeze interface-control drawings before cosmetic surfacing so industrial-design
   changes cannot silently move hardpoints.

## Release gates

1. Rated occupant, cargo and tow/assist loads, including dynamic and misuse factors.
2. Centre-of-gravity and anti-tip limits in travel, desk and canopy states.
3. Drive topology, motor torque, brake type, tyre, bearing and axle selections.
4. Table working load, support reactions, hinge pins and latch redundancy.
5. Canopy design wind speed, rain load, drainage slope and automatic retract strategy.
6. Mast actuator, holding brake, buckling margin and ingress protection.
7. Battery cell specification, enclosure venting, thermal paths and applicable transport standard.
8. Electrical architecture, isolation, grounding, EMC and emergency-stop behaviour.
9. Anthropometric targets, seat pressure mapping and accessibility requirements.
10. Target production volume and approved processes, which determine panel/tooling design.
11. Full tolerance stack, GD&T datum scheme, fastener schedule and service access.
12. Jurisdiction-specific machinery, mobility, furniture, battery and fire compliance review.

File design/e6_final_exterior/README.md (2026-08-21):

# WorkCore E6 最终外观设计包

> **状态更新：原始自由生成图及其未锚定结论已否决。** 它们未继承 E6-DFR3 STEP 几何，不得使用。纠正版与唯一有效的图像工作流位于 `step_anchored_v2/`。

本目录把 `docs/e6_object_character_and_mystery_brief.md` 作为首要设计准则，并以现有 STEP/CAD 为只读工程硬点。目标不是美化当前样机，而是给最终量产产品建立独立、可审查、可继续深化的外观母体。

## 设计结论

方向名：**Quiet Orbit / 静默轨道**。

E6 应被第一眼识别为一件低矮、完整、平静而有方向性的“个人场域仪器”。它的复古科幻来自轨道时代精密仪器的比例、温度和机械仪式；极简来自低位整体体量、少而准确的分缝和一致曲率；高级感来自真实材料、控制面差、装配精度与动作质感；神秘感来自闭合时未显露的能力，而不是模糊意图、隐藏安全信息或制造机器人表情。

闭合检验句：

> 闭合时像一件安静、完整、拥有未显露能力的新物品；展开时每个变化都自然得像它从来只能这样工作。

## 文件索引

- `01_design_dna.md`：最终造型语言、比例、界面语义和禁用语言。
- `02_states_and_engineering.md`：Follow / Ride / Café / Focus 四状态外观与工程边界。
- `03_cmf_and_release_gates.md`：量产 CMF、分缝、灯语、维护与逐级复测门槛。
- `04_image_prompts.md`：本轮概念图的统一提示词与负向约束。
- `05_visual_qa.md`：三张概念图的准则复核、已知偏差与下一阶段建模约束。
- `renders/`：本轮独立生成的外观概念图，不反写 CAD。
- `render_manifest.json`：视觉资产的尺寸与 SHA-256 清单。
- `step_integrity_baseline.json`：生成设计包前的 STEP 只读完整性基线。

## 非破坏性边界

- 不修改、不覆盖、不移动任何现有 `.step` / `.stp` 文件。
- 不把当前样机的箱体、彩色传感块、T 形梁或散落板件冻结为最终产品语言。
- 当前 STEP 仅提供轮组、人体、桌板、脚踏、桅杆、传感器、HMI、安全与服务硬点。
- 新造型后续应以独立 Class-A skin / 外观件 CAD 延续；在工程评审通过前不得侵入运动包络和安全接口。

本设计包是**最终外观方向冻结输入**，不是可直接开模的 Class-A/结构发布件。量产释放仍需通过本目录定义的工程、法规、人因、清洁、装配和场景验证门槛。

## 视觉资产

- `renders/01_hero_ride.png`：Ride 状态最终外观主视图。
- `renders/02_four_state_board.png`：Follow / Ride / Café / Focus 同一产品四状态板。
- `renders/03_cmf_detail_board.png`：CMF、感知带、隐私片、控制/急停与服务门细节板。

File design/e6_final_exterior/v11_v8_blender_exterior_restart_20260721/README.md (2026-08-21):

# WorkCore E6 V11 — V8 Blender exterior restart

V11 is an isolated exterior-design restart.  The four released V8 clean GLBs
are immutable spatial references; V9 and V10 visual geometry is not imported.

The workflow is deliberately split:

1. validate and import the V8 four-state references;
2. lock wheels, controls, contact surfaces and motion envelopes;
3. replace the visible body skin with one shared Blender design system;
4. review Follow closure and the lower-body mother surface before detailing;
5. render four-state review images;
6. only after visual approval, rebuild the accepted surfaces in canonical
   STEP/B-Rep and rerun the engineering gates.

Nothing below this directory is allowed to overwrite V8, V9, V10 or
`step_anchored_v2`.

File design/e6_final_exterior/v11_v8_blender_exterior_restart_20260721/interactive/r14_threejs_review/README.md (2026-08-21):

# WorkCore E6 · R14 Interactive Review

R14 外观、四种产品状态、开合结构与内部布局的 Three.js 交互评审页。项目独立位于 `interactive/r14_threejs_review`，没有修改原有 STEP 文件。

## 启动

需要 Node.js 22.13 或更高版本。

### 完全离线查看（推荐）

双击项目根目录的 `OPEN_R14_OFFLINE.cmd`。它只启动 `127.0.0.1:4173` 本机服务并打开默认浏览器，不访问在线 Site，也不会从网络下载模型、脚本、字体或材质。已经生成的 `dist/`、五个 GLB 和浏览器资源全部保存在本文件夹内。

也可以手动运行：

```powershell
npm start
```

然后打开 `http://127.0.0.1:4173/`。

### 开发与重新构建

```powershell
npm install
npm run dev
```

浏览器打开终端给出的本地地址。生产构建：

```powershell
npm run build
npm start
```

`npm start -- --hostname 127.0.0.1 --port 4173` 可显式指定本地监听地址。项目内的生产服务器会正确处理 Windows 静态资源路径。

## 交互

- 拖动旋转，滚轮缩放，点击模型结构查看或操作。
- 底部切换 Follow / Ride / Café / Focus；键盘快捷键为 `1`–`4`。
- 右上切换 Object / Internal / Exploded；快捷键为 `E` / `I` / `X`。
- `Review items` 列出靠背、桅杆、脚踏、桌板、扶手盖、设备仓、后服务门、前部感知带和固定摇杆。
- Internal 模式可按 Power / Drive / Control / Sense 筛选，并用 Section 滑块剖切外壳。

## 事实边界

- `ENDPOINT`：R14 存在源外观端点或定义铰点，可用于外观与布局评审，不等于机构成立。
- `PREVIEW`：仅为运动方向/维护空间预览，不能视作 STEP、碰撞、导轨、铰链或量产机构验证。
- `INSPECT`：仅定位固定结构，不执行运动。
- 内部模型 `workcore_internal_layout.glb` 是 E6-DFR3 历史包装子集，不是完整内部总成，也不是 R14 / DFR4 / DFR5 量产冻结真值。页面固定显示其来源、缺项和非量产边界。
- R14 QA 中的 `PASS` 只代表 Blender 外观保存文件检查通过，不代表机构运动、STEP 或量产结构验证通过。

## 已冻结的页面约束

- 摇杆始终固定外露在右扶手顶端，不随扶手盖或桌板移动。
- 左侧 Qi 区随左扶手盖运动；小屏幕固定在母表面，保持前高后低。
- Follow 为靠背折叠后的闭合表面意图，桅杆仍存在但处于低位；桌板不能从 Follow 直接弹出。
- Ride 默认展开脚踏；Café / Focus 默认收纳但允许手动打开。
- 差速轮维持半包覆，设备仓与后服务门在 R14 外观层只表现为齐平门缝。

## 模型资产

`public/` 内包含生产服务所需的扁平化模型资产：

- `workcore_r14_follow.glb`
- `workcore_r14_ride.glb`
- `workcore_r14_cafe.glb`
- `workcore_r14_focus.glb`
- `workcore_internal_layout.glb`
- `asset_manifest.json`（文件大小、来源修订与 SHA-256）

前三态/Focus GLB 来自 R14 Blender 四态文件；内部 GLB 保留 DFR3 历史基线身份，页面不会用它覆盖当前 R14 的 HMI、摇杆、靠背或桅杆设计。

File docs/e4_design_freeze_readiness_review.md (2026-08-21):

# WorkCore E4-DFR1 设计冻结与量产准备全面评审

评审角色：工业设计高级工程师/新产品开发负责人视角。评审目标不是证明模型“零错误”，而是判断产品是否具备进入设计冻结、DVT、PVT和量产的客观证据。

## 1. 结论先行

WorkCore 已从视觉概念推进到**系统架构明确、能够制造EVT工程样机的晚期概念/Alpha工程阶段**。人体优先级、桌板路径、设备仓与轮系、四轮差速、稳定性、电源热管理、桅杆设备和参数化干涉回归已经建立，这是有效的工程进展。

但当前仍是：

- **EVT0无人或配重样机：有条件进入**。前提是急停、远程断驱动、机械制动和实验室安全计划先实现。
- **载人测试：暂不放行**。必须先完成制动、稳定性、约束/逃生、电气隔离和风险审批。
- **设计冻结/DVT：不放行**。
- **PVT/量产：不放行**。

当前生成基线数据：1,090项自动分析/几何检查全部通过；收纳约867×740×690 mm、空载约121.1 kg，距900×760×700 mm目标保留约33×19.9×10.3 mm名义生产余量。36项量产证据门的完整度指标为18.1%，仍有30项P0门未关闭。该指标按closed=1、partial=0.5、open=0计算，只表示证据完整度，不表示认证成功概率。

项目的主要风险已不再是“外形是否能画出来”，而是缺少受控设计输入、法规路径、供应商实物参数、物理验证、生产过程能力和全生命周期质量证据。自动几何检查通过只能说明已编码的规则通过，不能覆盖未编码的风险。

## 2. 已经形成的可靠基础

1. **产品优先级正确**：乘员安全、逃生、驾驶和人体包络高于收纳和造型。
2. **关键P0几何进入参数化闭环**：桌板远离乘员、盖板闭合、设备仓全行程与轮系间隙、侧向移乘、脚踏和桅杆/顶棚构型均有实体检查。
3. **移动架构可继续开发**：250 mm四轮轮毂、左右摇臂、差速零转、50 mm额定越障和断电制动已形成计算边界。
4. **能源架构完整到系统级**：51.2 V/30 Ah LFP、PDU、双接触器、DC/DC、USB-C、停车态交流、电池/电子/设备仓分区热管理和桅杆90 W预算已定义。
5. **工程文件可重复生成**：STEP、GLB、BOM、接口、公差、几何/工程/移动/电气报告和离线评审页由同一参数源生成。
6. **审查能发现真实问题**：桅杆设备与顶棚扫掠、设备仓与轮系、模块重叠等问题曾被自动检查捕获并修正，说明模型开始具备工程工具价值。

## 3. 本轮补上的显性遗漏

### 3.1 主操控与安全服务接口

原模型没有实体化主操控器、机械急停、充电口、维修断电和手动制动释放。这些不是后期装饰件，而是载人系统的P0接口。本轮加入：

- 右侧默认可拆驱动控制舱和弹簧复位比例操纵杆；
- 左侧等价快拆安装基座，避免把右手操作写死；
- 与软件独立的双通道机械急停及防误触护圈；
- 后部密封充电口、可上锁维修断电和双动作手动制动释放；
- 后部可见/可听状态灯与蜂鸣接口；
- 桌板展开状态下对这些操控包络做实体净距检查。

这些仍是接口包络。操纵力、可达性、防水、诊断、连接器和最终造型必须通过DVP&R冻结。

### 3.2 生产BOM与仿真BOM分离

旧 `bom.csv` 同时列出折叠、收纳和展开状态实体，会把同一桅杆、相机或线束误当成多个生产零件。本轮新增去除状态重复的 `production_bom.csv`。它仍不是可下单BOM：大量项目只有接口ID，没有制造商料号、批准供应商、成本、寿命和替代策略。

### 3.3 量产证据层

新增：

- `production_readiness_report.json`：36项量产证据门和阶段结论；
- `requirements_traceability.csv`：产品/安全/人机/制造要求与证据；
- `risk_register.csv`：系统危害和待验证控制；
- `dvpr.csv`：32项验证计划；
- `supplier_release_register.csv`：19类关键供应件放行条件；
- `production_gate_checklist.csv`：G0、EVT、DVT、PVT到量产签署的门槛。

## 4. 全系统缺口审查

### 4.1 产品定义和法规

**现状**：目标人群、速度、质量、桌板/移乘/越障等边界已定义；中国标准域已被提及。

**缺口**：

- 产品是消费电子移动工作站、辅助移动设备还是医疗器械尚未由合格机构书面确认；
- 中国首发还是多市场同步、注册人/生产人/售后责任主体未冻结；
- “适用于居家移动困难老人”会显著影响预期用途、风险、标签和注册判断；
- 禁忌、护理人要求、坡度/天气/路面/体重/认知能力限制不完整；
- 没有条款级标准适用性矩阵。

**放行要求**：G0阶段先冻结预期用途和声明，并取得法规分类书面意见。中国现行 `GB/T 18029` 系列已包含2024年更新的静态稳定、强度、最大速度和小脚轮耐久等部分，不能继续沿用旧版本假设。[国家标准目录](https://openstd.samr.gov.cn/bzgk/std/std_list?p.p1=0&p.p2=GB%2FT+18029&p.p90=circulation_date&p.p91=desc)

### 4.2 风险管理和功能安全

**现状**：有安全状态机和初步FMEA，明确未知状态进入FAULT_SAFE。

**缺口**：没有正式风险管理计划、风险可接受准则、危害日志、DFMEA/FTA、单点故障矩阵、控制验证追踪和最终残余风险报告。控制器、制动器、位置传感器、急停和接触器还没有形成真实硬件架构。

如最终按医疗器械路径开发，风险管理需覆盖全生命周期、生产后信息和残余风险，ISO 14971:2019目前仍为确认有效版本。[ISO 14971](https://www.iso.org/standard/72704.html)

### 4.3 工业设计和CMF

**现状**：总体比例、隐藏杆件、壳体和材料方向存在；核心用户空间没有继续被收纳尺寸挤压。

**缺口**：

- 壳体仍是外形/厚度包络，缺少Class-A面、分件策略、拔模、分型线、筋柱、卡扣、螺钉塔、密封槽和模流输入；
- 没有间隙/面差地图、触摸等级、声品质、灯光逻辑和感知质量限度样；
- PC-ABS没有冻结树脂牌号、阻燃、UV、低温冲击、清洁剂和色差；
- 软包没有泡棉ILD/密度分层、压力分布、透湿、缝制纸样、接触材料和可拆洗结构；
- 设备仓、风道、杯液、雨水和冷凝的最低点/排水仍未工程化；
- 急停、控制器、相机/麦克风隐私状态尚需形成统一视觉语言。

最终CMF至少需要材料试片、颜色/光泽/纹理黄金样与上下限样、汗液/防晒霜/酒精/家用清洁剂、刮擦、UV和温湿老化。座垫若承担组织完整性管理，应纳入ISO 16840-2及其2024修订的相关测试域。[ISO 16840-2](https://www.iso.org/standard/66972.html)

### 4.4 人体工程和可用性

**现状**：CAD采用东亚保守人体包络，考虑老年侧移乘、低握力和无电逃生。

**缺口**：没有真实人体样本、压力映射、视野/盲区、操纵力、桌面键鼠任务、震动、热舒适、认知负担、误操作和照护员场景证据。590 mm座宽对多数用户宽松，但可能降低窄体型用户骨盆定位和扶手支撑，需要可调内衬或多规格软包验证。

应使用形成性样机快速迭代，再进行总结性关键任务验证；IEC 62366-1提供了把正确使用和使用错误纳入安全可用性过程的框架。[IEC 62366-1](https://www.iso.org/standard/63179.html)

### 4.5 机械、结构和DFMA

**现状**：参数STEP、质量估算、部分材料/工艺、关键净距和解析强度存在。

**缺口**：

- 没有生产2D图纸、GD&T、完整基准体系、焊缝符号、热处理、表面粗糙度和检验方法；
- 公差表仅覆盖少量接口，缺少全车关键特性和极限尺寸链；
- 没有紧固件等级、扭矩、锁固、螺纹啮合、粘接剂、表面预处理和防错；
- 桅杆绕绳、防坠、锁销、桌板锁、移乘铰链、脚踏和摇臂缺少孔边承压、屈曲、疲劳和磨损结果；
- 焊接底盘没有夹具基准、焊接顺序、变形补偿、焊后加工和NDT策略；
- 维修工具、拆装方向、工时、重件支撑和维修后复测没有验证。

GB/T 18029.8-2024已现行，静态、冲击和疲劳不能由有限解析计算替代。[GB/T 18029.8-2024](https://openstd.samr.gov.cn/bzgk/gb/newGbInfo?hcno=5A6D6D1A9F44450B5EAE4B7C5C998C28)

### 4.6 电气、热和电池

**现状**：功率、电量、线径压降、配电层级和热区已建立。

**缺口**：没有电气原理图、连接器/针脚、保险曲线、接触器短路能力、预充参数、绝缘/接地、线束固定点、束内降额、EMC滤波和真实风道压损。电芯、BMS、充电器、DC/DC、逆变器、风扇和接插件均未冻结精确料号。

LiFePO4不能只按“更安全”处理；需完成整包传播、浸水、碰撞、过充、外短、BMS故障和泄压验证。运输前必须获得适用于最终电池型号的UN 38.3报告和试验概要；UNECE已发布第8修订版及2025年修正。[UNECE UN试验和标准手册](https://unece.org/transport/standards/transport/dangerous-goods/un-manual-tests-and-criteria-rev8-2023)

### 4.7 控制软件、网络与隐私

**现状**：状态和互锁原则清晰。

**缺口**：没有软件需求、系统/软件架构、任务时序、看门狗、故障码、诊断覆盖、版本签名、回滚、校准管理、自动测试和发布流程。联网计算、摄像和麦克风带来未经授权运动、数据泄露和无感采集风险。

必须把运动安全域与联网/娱乐域隔离；无线或AI模块不得直接提供驱动许可。相机/麦克风需要硬件静音、不可伪造的物理状态指示、默认隐私状态、数据保留/删除策略和离线工作模式。

### 4.8 EMC和环境

**现状**：线束分区和热管理原则存在。

**缺口**：没有EMC预兼容、ESD、辐射/传导抗扰、无线共存、接地阻抗、雨淋、温循、冷凝、尘土、盐雾、堵转和滤网堵塞结果。ISO 7176-21已在2025年发布新版，不能继续默认2003/2009版为现行国际依据。[ISO 7176-21:2025](https://www.iso.org/standard/82763.html)

### 4.9 供应链和成本

**现状**：部分成熟供应件有包络和参考来源。

**缺口**：绝大多数COTS只有类别或候选家族，没有可采购料号、交期、最小起订、EOL通知、第二来源、供应商质量协议、首件和变更控制。也没有成本BOM、目标成本、模具/工装投资和保修成本模型。

任何供应商包络、连接器、固件或材料变化都必须进入ECN和接口复核，不能由现场修孔或软件补偿。

### 4.10 制造、质量和试产

**缺口基本完整开放**：没有工艺流程图、PFMEA、控制计划、作业指导书、夹具、量检具、MSA、关键特性能力目标、黄金样/限度样、100% EOL测试、序列号/电池/固件追溯、返工许可和PVT良率/节拍数据。

若走医疗器械路径，质量体系必须覆盖设计、供应、生产、交付和服务，而不是只在认证前补文档；ISO 13485:2016当前仍为确认有效版本。[ISO 13485](https://www.iso.org/standard/59752.html)

### 4.11 包装、运输、售后和退役

**缺口**：约118 kg整机禁止徒手装入后备箱，但尚无量产装载附件和包装方案。需设计滚入/升降辅助、系固点、包装振动跌落、防潮、危险品标签、仓储SOC、长期停放、备件、维修培训、事故数据、召回和电池回收流程。

## 5. 开发阶段和放行顺序

### G0：分类与设计输入

冻结预期用途、法规分类、目标市场、风险可接受准则、QMS责任、需求追踪、标准矩阵和DVP&R。G0未关闭，不得对外冻结“量产规格”。

### EVT0：无人底盘和安全链

只允许配重/假人：急停、远程断驱动、制动、接触器、看门狗、零转、电源、热和基本故障注入。出现任何非预期运动即停止。

### EVT1：完整机构和形成性人机

桌板、移乘、脚踏、桅杆、顶棚、设备仓、进水、热、EMC预扫和耐久。先静态人机模型，再经安全审批进行受控低速载人。

### DVT：设计意图样机

所有材料、供应商、软件和图纸接近最终状态；执行法规、结构、稳定、制动、环境、EMC、电池、可靠性、可用性和包装DVP&R。任何P0测试失败触发设计变更和回归。

### PVT：生产意图

使用量产工装、生产供应商、作业员和EOL设备制造至少一个统计上有意义的试产批；验证过程能力、良率、节拍、追溯、返工和服务。

### SOP：量产放行

最终风险管理报告、设计转移、DVP&R、供应商放行、PFMEA/控制计划、PVT问题和标签/说明书全部签署后才允许量产。

## 6. 量产数据包最低目录

1. 受控产品需求、系统需求和追踪矩阵。
2. 法规分类、适用标准和符合性计划。
3. 风险管理计划/报告、危害日志、DFMEA/FTA、PFMEA。
4. 3D主模型、2D图、GD&T、关键特性、材料/CMF和软件基线。
5. 电气原理图、PCB、线束图、针脚、保护协调和热设计。
6. 生产BOM、AVL、成本、供应商质量协议和变更通知。
7. DVP&R、原始数据、测试报告、偏差和回归记录。
8. 工艺流程、工装、作业指导、控制计划、MSA和EOL。
9. 包装、物流、UN38.3、仓储、标签和IFU。
10. 服务手册、备件、维修后测试、网络安全维护和退役回收。

## 7. 不得使用的结论

在上述门槛完成前，不得使用“生产级”“零风险”“已满足全部轮椅标准”“适合所有老人”“可在任何天气/坡面使用”“电池绝对安全”“自动检查零失败即可以载人”等表述。

当前准确表述是：**WorkCore E4-DFR1已具备受控EVT工程样机输入；量产证据仍显著不足，设计冻结、DVT、PVT和量产均为NO-GO。**

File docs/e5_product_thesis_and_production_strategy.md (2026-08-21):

# WorkCore E5 产品定盘：个人具身智能工作体

> 历史状态：E5 的“受控企业/实验室首发”场景判断已被 E6 的“家—社区—咖啡馆”个人工作伴体覆盖；安全、上下文连续、极简和量产证据原则继续有效。当前文件见 `docs/e6_product_definition_and_strategy.md`。

状态：产品宪法与量产收敛文件。E5 不推翻 E4 的总体形态、人体包络、双扶手、内藏桌板、智能桅杆和四轮底盘；它冻结产品为什么存在、首发为谁服务、哪些功能属于核心、哪些必须模块化或删除。几何和安全参数仍以 E4 工程基线及后续实物验证为准。

## 0. 结论先行

WorkCore 的正确品类不是“带桌子的电动轮椅”，也不是“会移动的电竞椅”，而是：

> **以人为中心、能携带任务上下文移动的个人具身智能工作体。**

它把坐姿支撑、工作界面、空间感知、本地 AI、供能、隐私和安全移动做成一个连续身体。用户不是把电脑搬到另一把椅子上，而是让自己的工作上下文随身体一起到达。

这一定义成立的前提，是首发只解决一个高价值问题：

> **让需要长时间深度工作、又必须在受控空间中频繁改变位置的人，不中断任务、不反复布置设备、不依赖他人完成移动。**

首发用户不是泛化的“90% 年轻极客 + 10% 老人”。这个比例会让一台产品同时承担消费电子、办公家具、轮椅、户外装备和照护设备五套冲突目标。E5 冻结为：

- **首发用户**：AI/机器人研发、数字内容制作、工业/实验室监控等高价值知识工作者；工作发生在园区、实验室、演播/制作空间和大户型室内等可管理环境；其中优先覆盖存在轻中度移动限制、疲劳、伤后恢复或无障碍需求的人。
- **首发购买者**：企业、实验室、工作室和无障碍雇主，采用带现场适配与维保的租赁/项目制，而不是直接面向所有消费者铺货。
- **不在首发声明内**：无人监管的高龄照护、医疗康复、公共道路、复杂户外越野、任意住宅、任意汽车后备箱和通用自动驾驶。

这不是退缩，而是建立跨时代产品的必要克制。初代产品必须先把一个完整体验做到不可替代，再扩展场景。

## 1. 产品存在性：必须比“笔记本 + 桌子 + 电动椅”多出什么

### 1.1 三个不成立的场景

以下场景不值得用 WorkCore 解决：

1. **普通固定办公**：一张好桌、一把好椅和一台笔记本更便宜、更轻、更易维护。
2. **纯代步**：成熟电动轮椅已经能以更低重量和价格提供移动。WHILL Model C2 的公开规格包括约 18 km 续航、约 50 mm 越障和四轮独立悬挂，说明“漂亮、灵活的电动椅”本身不是空白市场。
3. **偶尔户外创作**：折叠桌、移动电源和遮阳伞足以满足低频需求，不应让整车永久背负顶棚、强逆变和复杂通信的成本。

如果用户的核心任务可以被这三种组合轻松替代，WorkCore 就没有存在必要。

### 1.2 唯一值得做的场景

WorkCore 应服务“上下文切换成本极高”的人：

- 同时使用多路传感、音视频、模型和专用设备；
- 需要在同一栋建筑或受控园区内多次移动；
- 每次移动后都希望恢复同一个屏幕、灯光、相机、麦克风、文件、网络和 AI 会话；
- 不能或不愿反复搬运设备、插线、调姿和重新布置工位；
- 对隐私、本地推理、持续供电和物理安全有刚性要求。

产品价值不是“每小时多走几百米”，而是每天消灭数十次任务中断。北极星指标因此不是续航里程，而是：

> **从坐下/到位到恢复可工作的时间，以及一天内保住的连续高质量工作分钟。**

### 1.3 形态为何必须有人坐在其中

具身智能不等于一定要做成人形机器人。WorkCore 的“身体”由使用场景决定：

- 人是意图、判断和责任主体；
- 座舱是稳定的人机基准；
- 桅杆是可升降的感知器官；
- 桌面和扶手是动作与信息界面；
- 底盘是低速位置改变能力；
- 本地计算是记忆、理解与编排能力；
- 硬件安全链是反射神经，AI 无权越过。

这比追随人形机器人更贴合首发任务，也能立即使用当前供应链落地。

## 2. iPhone 级产品观：不是功能多，而是没有可分离的体验

WorkCore 的跨时代性不应来自更多按钮、更多屏幕或更多执行器，而应来自六条不可妥协的统一原则。

### 2.1 一个身体

外观看起来必须是一个完整物体，不是轮椅、桌子、遮阳篷、设备箱和相机架的拼装。轮、抽屉缝、紧固件、线束、传感器和急停都要进入统一的结构与视觉秩序。

### 2.2 一个工作面

用户面对的主界面只有展开后的实体桌面。左扶手小屏只显示状态、隐私、能量和一步确认；它不发展成第二套应用生态。手机无线充电是“放下即接管身份和上下文”的入口，不是装饰性配置。

### 2.3 一个动作

从行驶态到工作态，目标是一次明确意图触发、系统自动检查、机构按安全序列完成。用户不应分别操作盖板、滑架、桌板、桅杆、灯光、相机和应用。

### 2.4 一个视线

桅杆必须围绕乘员眼位工作，而不是让乘员适应固定相机。相机、补光、麦克风和状态灯形成一个“智能眉梁”；系统根据座高、靠背角和头部位置选择感知高度，避免乘员头部遮挡前向视场，也避免横梁侵入头部心理空间。

### 2.5 一个安全态

任何位置、锁止、占用或通信状态未知时，系统都回到可解释的安全态。AI 可以建议、预判和编排，不能直接授予牵引、制动释放和危险机构动作权限。

### 2.6 一个声音

电机、风扇、锁扣、桌板和提示音必须作为统一声品质设计。高端感首先来自安静、确定、无松旷，而不是昂贵饰面。

## 3. 对现有设计的定盘与删减

### 3.1 必须保留：构成产品身份的五件事

| 核心 | 定盘决定 | 原因 |
|---|---|---|
| 低矮一体化座舱与四轮底盘 | 保留当前总体比例、744 mm 级宽度和隐藏轮组语言 | 它建立稳定、可通门和非传统轮椅的辨识度 |
| 双扶手内藏双片桌板 | 保留“先前移、盖板复锁、再展开”的序列 | 它是移动与深度工作之间的关键形态转换 |
| 非对称扶手 HMI | 保留右侧可拆摇杆/授权键、左侧状态屏/Qi | 控制、身份、状态和工作转换被压缩到两处自然触点 |
| 智能桅杆 | 保留升降脊柱、视觉/音频/照明/环境传感 | 这是 AI 与现实世界建立共同视角的器官 |
| 安全移动底盘 | 保留断电制动、50 mm 额定越障目标、低速零转和机械逃生 | 让工作上下文真正能随人移动，而不是一件固定家具 |

### 3.2 保留但退居后台

- **后置越障拉杆**：保留为无人、维修/转运状态的隐藏工具，不作为载人越障卖点。它不应破坏后部完整面，也不增加乘员操作负担。
- **侧向移乘机构和骨盆约束**：作为无障碍配置和安全架构保留，但首发展示语言不医疗化。
- **设备仓**：保留模块接口，不再默认承诺“四个抽屉装下所有设备”。
- **零转**：保留为低速空间能力，不宣传为娱乐动作或持续高摩擦地面功能。

### 3.3 首发模块化，不进入基础整机

| 功能 | E5 决定 | 进入条件 |
|---|---|---|
| 顶棚/遮阳 | 户外工作包，不进入基础 SKU | 明确户外客户、风/雨/夹伤实测和可接受维护成本后 |
| 600 W 交流逆变器 | 岸电/专业设备包 | 只有不能由 USB-C PD 覆盖的真实设备清单达到购买阈值时 |
| 卫星通信 | 远程现场包 | 首发园区/室内不需要；5G/Wi-Fi 为默认 |
| 双笔记本高功率闭仓运行 | 取消默认承诺 | 改为一个通用计算仓 + 一个工具/存储仓；闭仓只运输或受控充电 |
| 照护员手柄、老人 UI | 后续照护 SKU | 独立预期用途、风险、验证和售后体系后 |
| 自动驾驶 | 软件研究功能，不进入首发承诺 | 先完成防撞、精准通门、自动泊位等限定辅助能力 |

### 3.4 应立即删除的复杂度

- 同一硬件同时面向“极客创作”和“无人监管老人照护”的市场声明；
- 任何把小屏做成完整操作系统的企图；
- 为覆盖极少数 330 W 游戏本而让所有基础整机永久携带逆变器；
- 为“看起来智能”而增加的装饰传感器、氛围屏和重复状态灯；
- 没有任务数据支持的抽屉数量、自动机构和通信制式；
- 把顶棚、60 mm 条件越障、后备箱兼容或全场景 AI 当作首发卖点。

## 4. E5 极简系统架构

### 4.1 WorkCore Body：身体与安全反射

底盘、座椅、电池、制动、脚踏、移乘和基本操控构成安全域。它能在所有上层计算失效时完成停车、驻车、机械逃生、手动释放和受控维修。

### 4.2 Context Surface：上下文界面

扶手、Qi 身份入口、状态屏和内藏桌板构成唯一工作界面。桌板不是附件，而是身体展开后的工作姿态。它的机构状态直接映射 AI 会话状态：桌面展开即恢复工作；桌面收回即保存并进入移动摘要。

### 4.3 Intelligence Spine：智能脊柱

桅杆集成可见光/深度感知、麦克风、定向补光、隐私硬件、环境传感和网络桥。首发不追求最多传感器，而追求经过标定的共同坐标系、低延迟时间同步和可验证的隐私状态。

### 4.4 Context Core：本地上下文核心

可更换计算/存储盒运行设备编排、多模态理解、本地检索和隐私策略。安全控制器与其物理隔离。计算代际可以升级，座舱、机构和安全认证资产不随芯片报废。

### 4.5 Dock：基础设施而不是更大电池

停靠底座提供充电、岸电、网络、数据同步和诊断。WorkCore 的长时工作能力应来自“到位即持续供能”，而不是继续增加整车电池、重量和运输难度。

## 5. 第一代产品的魔法时刻

跨时代产品必须能在一分钟内被理解。首发演示只展示一条完整链路：

1. 用户靠近，手机/密钥完成本地身份确认；
2. 坐下后，座椅、脚踏、扶手和约束状态被确认；
3. 用户说“继续刚才的工作”或按一次工作键；
4. 驱动安全断开，桌板按机械顺序展开，桅杆调到不被头部遮挡的位置；
5. 灯光、相机、麦克风、网络、文件和 AI 会话恢复到上一位置的状态；
6. 移动前，系统摘要当前任务、保存现场、收桌并在所有锁位确认后恢复驱动；
7. 到达底座后无感补能和同步。

验收目标：第一次见到产品的人无需讲解就能理解“它把我的工作带走了”。

## 6. 量产前真正遗漏的需求

当前 E4 已有 1,090 项自动检查全通过，但量产证据完整度只有 18.1%，30 项 P0 门未关闭，35 项 DVP&R 尚未执行，22 类关键供应件无一完全放行；169 行生产 BOM 中 123 行仍为自制/定制定义。产品的主要缺口不是再补一个功能，而是补齐以下系统需求。

### 6.1 体验需求必须数字化

| 指标 | E5 目标输入 | 验证方式 |
|---|---:|---|
| 到位后恢复上次任务 | ≤10 s；拉伸目标 ≤5 s | 30 次真实任务循环 P95 |
| 行驶态到可工作态 | ≤15 s | 含全部锁位确认，不以跳过安全步骤计时 |
| 工作态到安全可行驶态 | ≤10 s | 机构卡滞、物品遗留和传感故障注入 |
| 无电紧急离开 | ≤10 s 目标 | 低握力用户、黑暗和单手条件 |
| 800 mm 门精准通过 | 0.20 m/s 限速、无接触 | 不同门套、侧偏、低矮障碍 |
| 连续舒适工作 | 2 h 无不可接受压力/麻木/热湿 | 压力图、主观量表和人体样本 |
| 工作位耳旁噪声 | 建议目标 ≤35 dBA 稳态，动作声无尖锐冲击 | 消声/半消声环境和真实地面频谱 |
| 隐私状态识别 | 2 m 处一眼可辨，硬件不可伪造 | 断网、掉电、恶意软件和误操作测试 |
| 日常维护 | 过滤器/常用模块免拆座椅，5 min 内完成 | 服务工时与防错演练 |

这些是产品目标，不是现阶段已实现或法规合格声明。

### 6.2 具身 AI 的遗漏需求

- 所有传感器统一时钟、统一外参和生产线标定流程；
- 乘员头部、手部、桌面和行驶环境的可解释遮挡图；
- 相机物理遮挡、麦克风硬件静音及不可由主系统伪造的指示；
- 本地数据加密、用户可导出/删除、默认最小保留；
- 离线基本功能；云服务中断不能影响运动、桌板、逃生和本地任务恢复；
- 安全启动、签名 OTA、A/B 回滚、密钥轮换和维修授权；
- AI 与安全控制之间只通过最小、白名单化意图接口通信；
- 每个自动动作可被即时取消，系统解释“为什么没动”和“怎样恢复”。

### 6.3 工业设计遗漏需求

- Class-A 面、分件、拔模、分型线、筋柱、紧固和密封必须与结构共同冻结；
- 建立全车间隙/面差地图，减少不同缝宽和无意义装饰线；
- 触摸件只保留三类材料语言：温暖软触、精密硬触、耐撞底部；
- 所有高频接触面可耐汗液、防晒霜、酒精和常用清洁剂；
- 灯光只表达四类信息：可工作、可移动、隐私、故障；
- 控制整机可见紧固件类型、外露运动杆和色彩数量；
- 建立关门声、锁止声、风扇声和电机声的黄金样与限度样。

### 6.4 制造与商业遗漏需求

- 在 EVT 前建立目标成本 BOM、供应商料号、寿命、第二来源和停产策略；
- 解决当前生产 BOM 质量口径与整机质量报告不一致的问题，禁止状态实体或同一物理件重复计重；
- 首发基础 SKU 的整机目标质量建议由当前约 121 kg 向 **≤105 kg** 收敛，伸展目标 <95 kg；若达不到，必须把运输与场地服务写进商业模式，而不是要求用户搬运；
- 设立目标 ASP/COGS/毛利模型，并用 20 个真实采购意向验证，不用“高端用户愿意买”代替证据；
- 明确现场勘测、交付、培训、维保、备件和故障响应时间；
- 生产线 100% EOL 覆盖制动、急停、锁位、绝缘、传感标定、隐私硬件、通信隔离和序列号追溯。

## 7. 三道核心护城河

专利不能阻止大厂进入整个品类。真正的防御是：大厂即使看懂外形，也要重新付出机构可靠性、安全验证、标定数据、现场服务和用户工作流集成的成本。E5 只集中打造三道壁垒。

### 7.1 护城河一：Context Continuity Engine（上下文连续引擎）

它不是聊天机器人，而是把物理状态与数字任务绑定的本地系统：座椅占用、桌板、桅杆、位置、朝向、传感器、设备、文件、会话和权限共同形成“工作快照”。产品移动或变形时，系统以安全、隐私和能量约束恢复任务。

可保护资产：

- 物理构型到 AI 会话状态的映射和恢复方法；
- 多设备/多传感器的低延迟时间同步与场景快照；
- 企业现场使用数据形成的任务恢复、错误和人机协作数据集；
- 用户个人工作图谱和设备适配器生态；
- 本地优先隐私架构和可审计事件链。

这是最重要的长期软件与数据壁垒，也是用户换设备时真正产生迁移成本的地方。

### 7.2 护城河二：Safe Morphing Workspace（安全变形工作界面）

双扶手内藏桌板、先平移后展开、盖板重新锁闭、人体扫掠隔离、桌板与驱动互锁、无电逃生构成一个完整机构与控制系统。基础的“轮椅托盘”“扶手内藏托盘”已有大量先例，不能把单一桌板概念当作新颖性。专利价值必须落在具体的运动链、机械顺序约束、双通道状态确认、人机净空和安全状态组合。

可保护资产：

- 左右双片桌板从扶手内收纳到乘员前方拼合的特定运动链；
- 盖板复锁后才允许展开的机械因果链，而非仅软件提示；
- 桌板、移乘扶手、脚踏、占用和牵引许可的组合状态机；
- 单手/低握力无电释放与错误状态恢复；
- 机构寿命、夹伤、污染和极限公差数据库。

### 7.3 护城河三：Intelligence Spine（遮挡感知智能脊柱）

桅杆围绕乘员和任务自动调整感知姿态，使人、桌面和环境处于统一坐标系，并提供物理隐私。它不是把相机装在杆上，而是“知道人的头在哪里、什么被遮挡、何时应收纳、何时数据不可信”的感知模块。

可保护资产：

- 基于座椅/靠背/头部状态选择桅杆高度与传感器朝向；
- 对乘员头部遮挡、顶棚/桌板遮挡和运动扫掠的联合求解；
- 相机、深度、麦克风和补光的工厂标定治具与补偿算法；
- 物理隐私遮挡件与安全域隔离；
- 可更换传感梁和计算盒的接口规范。

## 8. 专利与知识产权组合

### 8.1 不押注一件“大专利”

推荐形成“外观 + 发明/实用 + 软件秘密 + 验证数据 + 品牌”的组合：

1. **核心产品形态外观族**：收纳、行驶、工作三种状态；整机与局部设计分别提交；重点保护侧面连续体、双扶手、智能眉梁和隐藏轮组关系。
2. **安全变形工作界面专利族**：机构链、复锁顺序、双片拼合、互锁和逃生。
3. **遮挡感知智能脊柱专利族**：乘员相对感知、自动高度、标定和隐私硬件。
4. **上下文连续引擎专利族**：物理状态驱动的任务快照、恢复、权限与能量约束。
5. **辅助专利**：无人越障拉杆的隐藏结构与助力模式、Qi 手机在位与扶手盖板互锁、可更换计算/存储热管理盒。
6. **商业秘密**：控制参数、标定数据、可靠性失效库、供应商窗口、工装和现场部署方法。

### 8.2 已知拥挤区与撰写原则

早在 1979 年就有可收纳轮椅托盘；US8474384B2 已公开扶手壳体内的滑动/折叠托盘及可选执行器；近期也有可调轮椅桌面。由此可见：

- 不申请“轮椅上有桌子”或“扶手里藏桌子”这种宽泛权利要求；
- 不用营销名称代替技术因果关系；
- 每一族都同时写出机构、传感、控制、安全降级和服务替换的多组实施例；
- 在对外公开新的机构视频、爆炸图和状态机之前先取得优先权；
- 由专利律师完成正式新颖性检索、权利要求布局和 FTO。本文件只定义假设，不构成可专利性或不侵权结论。

## 9. 大厂为什么不会立刻赢，以及我们怎样避免自我欺骗

大厂不是被专利“挡住”的，而是被初期市场结构和执行密度拖慢：

- 首发市场规模对大厂不够大，但对小团队足够建立 100～500 台的高价值样本；
- 产品横跨座椅、移动、安全、电池、机构、边缘 AI、现场安装和售后，组织协同成本高；
- 真实优势来自数万次桌板循环、故障注入、人体适配、标定和现场任务数据，不在渲染图；
- 企业客户的工作流、身份、设备和本地数据一旦集成，替换成本高；
- 可升级计算盒使产品不因 AI 芯片代际变化整体淘汰。

但必须承认：如果 WorkCore 只剩“酷外形 + 通用大模型 + 现成轮椅底盘”，大厂可以迅速复制。防御成立的必要条件，是在两年内把三道护城河做成可测量资产，而不是继续扩充功能列表。

## 10. 量产收敛路线

### 10.1 未来 90 天：只回答四个问题

1. **必须性**：访谈/跟随至少 20 名目标用户，记录一天内真实移动、设备重布置和任务恢复次数；取得不少于 5 个付费或有预算的试点意向。
2. **魔法时刻**：做一台可坐的 1:1 人机样机和一套可运行的桌板/桅杆演示，验证 15 秒展开、10 秒任务恢复和头部不遮挡。
3. **安全底座**：完成无人滚动底盘、急停、断电制动、远程断驱动和物理故障注入，不做未经放行的载人炫技。
4. **成本与质量**：清理 BOM 计重，冻结基础 SKU，移出顶棚/卫星/逆变器，锁定电池、轮端、制动、滑轨、执行器和计算盒候选供应商。

90 天终止条件：若真实用户没有高频上下文切换、没有付费意愿，或魔法时刻仍像“展开一张桌子”，应停止整机扩张，转而只做桌板机构或智能脊柱模块。

### 10.2 EVT：证明系统可安全工作

- 3 台无人/配重底盘：制动、驱动、热、电源、EMC 预扫和故障安全；
- 3 台机构台架：桌板、移乘、脚踏、拉杆、桅杆全寿命与夹伤/污染；
- 2 台人体样机：只在前置安全门通过后开展低速、受控、伦理批准的形成性测试；
- 上下文连续引擎跑通一条完整任务链，不开发应用商店。

### 10.3 DVT：证明设计意图可被重复制造

- 建议 12～20 台设计意图样机，覆盖法规、结构、环境、EMC、软件、网络安全、人体、声振和耐久；
- Class-A、间隙面差、CMF 黄金样、2D 图/GD&T、线束、EOL 和维修流程冻结；
- 三个试点现场连续运行，统计任务恢复率、干预次数、故障、维护工时和真实使用频率。

### 10.4 PVT：证明工厂和服务体系能交付

- 建议 30～50 台生产意图试产；样本量最终由风险、过程能力和法规要求确定；
- 验证工装、PFMEA、控制计划、MSA、关键特性能力、EOL、追溯、包装、运输和现场安装；
- 量产放行以缺陷率、安全事件、任务恢复成功率和服务工时为条件，不以“按期发布”替代。

## 11. 首发产品指标板

| 维度 | 唯一关键指标 | 失败红线 |
|---|---|---|
| 必要性 | 每位目标用户每天被消除的有效任务中断次数 | 真实场景中低于 3 次/天 |
| 体验 | P95 到位后恢复任务时间 | >10 s 或需要多应用手动操作 |
| 形态 | 陌生用户能否一眼识别收纳/行驶/工作状态 | 需要培训才能判断 |
| 安全 | 所有单一可预见故障进入可解释安全态 | 任一未知状态仍能获得运动许可 |
| 可靠性 | 桌板/桅杆关键循环与故障恢复 | 卡滞后需拆壳才能逃生 |
| AI | 离线完成身份、状态、任务恢复和基本感知 | 断网即失去核心体验 |
| 制造 | 基础 SKU 定义、量产 BOM 与供应商释放 | 继续把概念包络当作可采购零件 |
| 商业 | 付费试点、部署成本、维护工时 | 只能靠消费电子式一次性销售成立 |

## 12. 不可妥协的产品戒律

1. 不再增加没有真实任务证据的可见功能。
2. 不用 AI 掩盖机构、安全和人体工程的不成熟。
3. 不把“能装进去”写成“用户会需要”。
4. 不把自动几何检查通过写成量产、认证或人体安全通过。
5. 不让小屏成为复杂性的避难所；常用动作必须直觉、可触、可取消。
6. 不让云、无线或主 AI 进入运动安全许可链。
7. 不牺牲乘员空间换取漂亮的收纳数字。
8. 不追求所有人的第一代；先成为一小群高价值用户不可替代的身体。
9. 计算可换代，座舱不报废；模块可维修，整机不因单件故障退役。
10. 每一次新增都必须同时回答：谁每天用、替代什么、增加多少质量/成本/风险、形成什么独占资产。

## 13. 外部事实与边界依据

- [WHILL Model C2 官方产品对比](https://whill.inc/us/whill-power-chairs/)：成熟电动移动产品已覆盖美观、紧凑转向、约 50 mm 障碍和便携拆分，WorkCore 不能只以移动参数建立新品类。
- [WHILL Autonomous Service](https://whill.inc/ca/mobility-service/how-it-works/autonomous-drive)：截至页面当前披露，限定场地自主移动已在机场等受控环境商业部署，并依赖场地评估、地图、监控、培训和持续运营；支持 WorkCore 从受控 B2B 场景起步，而不是首发承诺通用自动驾驶。
- [NVIDIA Jetson AGX Thor 官方说明](https://docs.nvidia.com/jetson/agx-thor-devkit/user-guide/latest/index.html)：边缘平台已面向 physical AI 与机器人提供本地高算力，说明可更换本地计算盒具备现实供应基础，但也说明“用了某块 AI 芯片”本身不能构成护城河。
- [ISO 13482:2014](https://www.iso.org/standard/53820.html) 与正在形成的 [ISO/FDIS 13482 第二版](https://www.iso.org/standard/83498.html)：载人/服务机器人必须从可预见的人机接触和功能安全出发；最终分类仍需合格机构确认。
- [ISO 7176-14:2022/Amd 1:2025](https://www.iso.org/standard/72408.html) 与 [ISO 7176-21:2025](https://www.iso.org/standard/82763.html)：动力/控制和 EMC 仍是载人移动系统不可绕过的工程输入。
- [US8474384B2 扶手内藏折叠托盘](https://patents.google.com/patent/US8474384B2/en)、[US4223944A 可收纳轮椅托盘](https://patents.google.com/patent/US4223944A/en) 与 [US12569383B2 可调轮椅桌](https://patents.google.com/patent/US12569383B2/en)：证明基础桌板概念属于拥挤先例区，专利必须聚焦 WorkCore 的具体运动、安全和上下文组合。

## 14. 最终定盘

现有设计值得笃定，但笃定的是它的**产品骨架**，不是每一个已经画出来的附件：

- 笃定座舱、双扶手、内藏桌板、智能桅杆和低速移动是一体化新品类的正确形态；
- 笃定右侧操控、左侧状态/Qi 和隐藏越障拉杆应被保留；
- 笃定 AI 必须拥有现实世界的共同视角、上下文和本地记忆；
- 同时坚决把顶棚、卫星、强逆变、双高功率设备仓、照护声明和通用自动驾驶移出首发核心；
- 在任何新的外观深化之前，先完成必要性、魔法时刻、安全底座、BOM/质量和专利优先权五项闭环。

WorkCore 要成为的不是“功能最全的椅子”，而是第一台让人感到 **AI 有了与自己共同工作的身体** 的产品。这个概念足够远，但它的第一步非常具体：坐下、展开、接续任务、安全移动，再无多余。

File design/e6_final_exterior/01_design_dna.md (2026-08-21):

# 01 — Quiet Orbit 设计 DNA

## 1. 物品原型

E6 不是“轮椅 + 桌子 + 跟随箱 + AI 屏幕”的拼装，也不是办公椅、护理设备、配送机器人、工具车或豪华概念车。它是一个可在不同关系中变形的**个人场域仪器**：

- Follow：安静随行的低位物体；
- Ride：以人为视觉主体的移动座舱；
- Café：主动给另一人留出位置的社交家具；
- Focus：建立边界但不封闭人的个人工作场。

目标受众首先是创作者、AI/机器人研发者、影音制作人、实验室与园区知识工作者。产品要足够温暖以进入日常空间，足够精确以进入专业空间，也足够清楚以让旁观者无需猜测它的意图。

## 2. 形式语法

### 低位整体

- 下体是一枚软梯形、超椭圆截面的“矿石基座”，视觉重心贴地。
- 四轮上半部由深色内裙吸收，但胎面接地、运动方向和安全边界必须可读。
- 上壳是连续嵌套体，不出现方箱叠方箱、抽屉墙、独立托盘或零件陈列感。
- 前后并非镜像：前端更薄、更指向；后端略厚，承担服务、能量与稳定感。

### 三条可见线

日常只保留三类主线：

1. 低位感知地平线：连续但不伪装成一整块黑玻璃；
2. 上甲板变形线：桌、座、脚踏从同一几何秩序中出现；
3. 后部服务门：齐平、可识别、可授权开启。

其他分缝从属于装配与维护，不得成为装饰。避免随机黑缝和无功能假开口。

### 曲率纪律

- 主曲率参考 R40–70 mm；关键体量可使用更大视觉半径形成长弧面。
- 次级过渡参考 R12–20 mm；触边与装配边参考 R2–4 mm。
- 大面追求连续、受控的高光流动；不能用“全部相同圆角矩形”代替真正曲面。
- 桌板、扶手、传感舱、服务门共享截面家族和切线关系。

## 3. 复古科幻的正确来源

采用“晚 1960s 轨道研究仪器经当代量产重译”的气质：温暖矿物色、低饱和金属、烟熏光学窗口、精确机械控制、缓慢而可信的显露动作。它应让人联想到为长期使用而制造的未知仪器，而不是影视道具。

明确禁用：

- 火箭鳍、舷窗、假散热孔、宇航服条纹、雷达 UI 等直白怀旧符号；
- 机器人眼睛、嘴、表情、RGB 呼吸灯和拟人化反馈；
- 赛博朋克、蒸汽朋克、军用攻击性、汽车格栅与驾驶舱包围；
- 大面积钢琴黑、镀铬、亮白家电塑料、假木纹和装饰性灯带；
- 医疗管架、护理绗缝、代步车、星形办公椅、行李拉杆或工具车抽屉语言。

## 4. 神秘感与信任

神秘的是尚未显露的能力，不是意图：

- 可以隐藏桌机构、桅杆行程和收纳能力；
- 不得隐藏前后方向、即将运动、驻车、故障、接管、急停和隐私状态；
- 工作相机必须有肉眼可见的实体隐私片与机械图形；
- 导航感知和内容采集必须使用不同语义；
- 开放侧、可接近侧和服务侧在两米外应可判断。

## 5. 关键识别件

- **感知地平线**：深烟茶色的低位功能带，按 IR、RF、超声、声学膜的真实材料分段，却在视觉上保持一条安静水平线。
- **后脊柱**：Ride 时低矮、略后收；只在驻车 Focus 时升为窄而精确的“观测脊柱”。
- **观测檐**：薄型横向传感舱，避免巨大 T 形路牌；实体隐私片是其标志动作。
- **显露桌叶**：从扶手/上甲板可信缝线中先前移再展开，闭合时不留下托盘感。
- **方向光标**：前部两个短型、低亮功能光标，不构成人脸。
- **真实急停**：保留机械红色、清晰可达，作为安全器件而非造型点缀。

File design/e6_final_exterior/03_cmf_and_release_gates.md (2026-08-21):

# 03 — CMF、细节与量产复测门槛

## 主 CMF：Lunar Archive

| 区域 | 建议 | 目标与禁忌 |
|---|---|---|
| 上壳 | 暖月岩灰 `#C8C2B7`，细砂哑光，约 8–12 GU | 有矿物温度，不做医疗白或亮面家电塑料 |
| 下基座/轮拱 | 深烟褐 `#292623`，耐刮微纹理 | 隐藏污损并压低重心，不伪装轮胎接地 |
| 感知带 | 烟熏茶褐 `#302923` | IR/RF/超声/声学使用各自真实透过材料，不做假一体黑玻璃 |
| 金属揭边 | 香槟钛色 `#A99C83` 低光阳极氧化 | 只在精密边界少量出现，避免镀铬奢侈感 |
| 软包 | 炭灰褐 `#3A3834` 可拆洗 3D 针织 | 无医疗滚边、菱格绗缝、汽车桶椅语言 |
| 桌面 | 浓缩咖啡灰 `#40372F`，低反光耐指纹 | 不用假木纹；边缘温润、耐碰且可更换 |
| 功能警示 | 琥珀 `#D88332` + 真实急停红 | 彩色可见面积低于约 1%；颜色不作为唯一信息通道 |

建议量产材料：纹理 PC-ABS/短纤增强工程塑料外壳、粉末涂层或阳极氧化铝骨架、可替换 TPE 下缘耐撞条、光学级 IR 窗、RF 透波聚合物、疏水声学膜、可拆洗阻燃针织软包。具体牌号必须经阻燃、VOC、UV、耐汗、清洁剂、耐候、跌落和供应链验证后冻结。

## 分缝、清洁、服务

- 上表面避免朝天缝；桌机构湿区设置刮水唇、集水槽和侧向排水。
- 后部采用齐平“船艉式”服务门，集中充电、维修断电、制动释放和诊断。
- 传感窗、轮拱侧裙、下缘耐撞条独立可换；门内或底部使用防脱紧固件。
- 触摸面与维修面用不同纹理/触觉；戴手套时仍可辨识。
- 平滑不等于胶死：关键面板不得依靠撬壳或破坏性拆胶来更换。
- 维护门开启、隐私片位置、制动释放和断电状态应具有近场物理确认。

## 灯语纪律

- 无装饰性连续灯带、RGB 呼吸或拟人眼睛。
- 前部两个短型方向光标表达即将移动/运动方向；停稳显示稳定水平短线。
- 故障/接管使用分段琥珀符号并配声音或触觉，颜色不单独承担语义。
- 桌、脚踏或服务门动作时，仅运动边缘出现低亮琥珀扫掠，锁止后熄灭。
- Focus 可用 3000–3500 K、高显色定向任务光；不得向旁观者或相机直射。

## 量产释放门槛

每一门都要保留证据、失败项、纠正措施和复测结果；不以渲染图通过代替工程通过。

### G0 — 设计意图冻结

- 四状态轮廓、主曲面、高光、前后/开放侧/服务侧可读性评审；
- 禁用语言清单逐项检查；
- 受众场景板和 1:1 关键尺度带审。

### G1 — 数字包络

- Class-A 曲率连续性、最小拔模/壁厚/圆角/公差预审；
- 轮胎、人体、桌板、脚踏、桅杆、线束和服务工具的全行程干涉分析；
- 传感视场、射频/声学透过、散热/泄压、排水和清洁死角分析。

### G2 — 物理外观样件

- 1:1 泡沫/打印/软模样件的姿态、转移、对坐、工作与旁观者理解测试；
- 真实材料色差、光泽、纹理、指纹、刮擦、拼缝、高光和灯语评审；
- 戴手套服务、无电释放、急停、隐私片与儿童/宠物近场验证。

### G3 — 工程验证样机 EVT

- 环境、热、振动、跌落/冲击、液体、清洁剂、UV、EMC、无线与传感性能；
- 所有状态互锁、夹点、制动、倾覆、超载、误用、单点失效和恢复路径；
- 外观件拆装次数、紧固件保持、异响、磨损、轮拱污染和服务工时。

### G4 — 设计验证 DVT

- 量产意图模具/材料/工艺件的尺寸链、CPK 目标、色差/光泽窗口和配合面；
- 第 5/50/95 百分位人因、ODD 场景、可用性、隐私与旁观者信任复测；
- 法规/认证、阻燃/VOC、运输、包装、维修与回收设计验证。

### G5 — 生产验证 PVT

- 供应商首件、治具、检具、EOL 测试、追溯、返修和换件流程；
- 小批量道路/园区真实场景、长期污损、动作寿命、噪声和客诉闭环；
- 外观限度样、Golden Sample、灯语/安全标签、作业指导书和出厂抽检冻结。

### G6 — 量产后持续验证

- 早期失效、近失事件、维修数据、隐私反馈和场景漂移进入同一问题闭环；
- 任何改变 CMF、壳体、传感窗、灯语或运动件的 ECO，按影响范围回归 G1–G5。

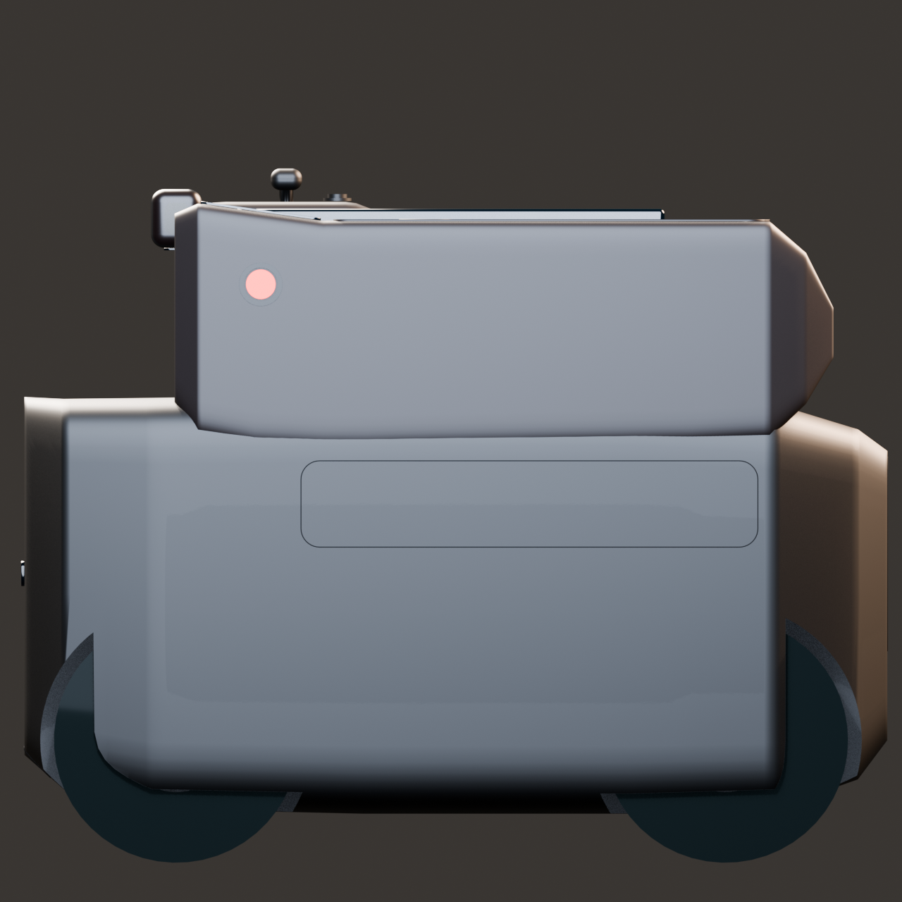
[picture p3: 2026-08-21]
design/e6_final_exterior/v11_v8_blender_exterior_restart_20260721/renders/final/r14/follow/06_follow_left.png

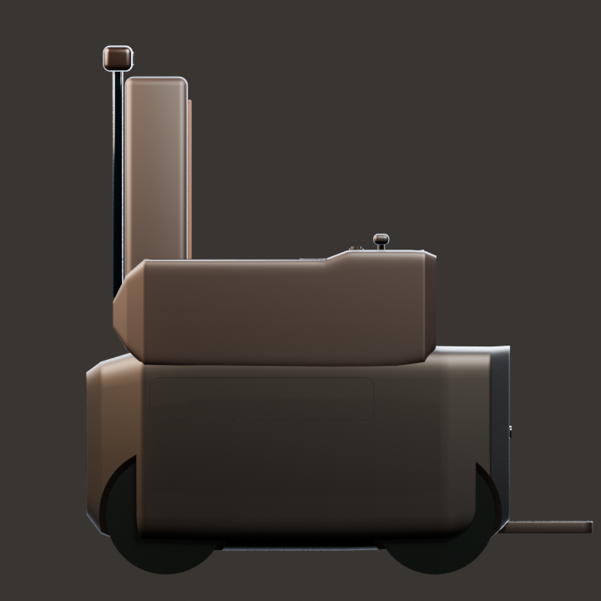
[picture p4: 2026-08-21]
design/e6_final_exterior/v11_v8_blender_exterior_restart_20260721/renders/preview/r14/ride/ride_right.png

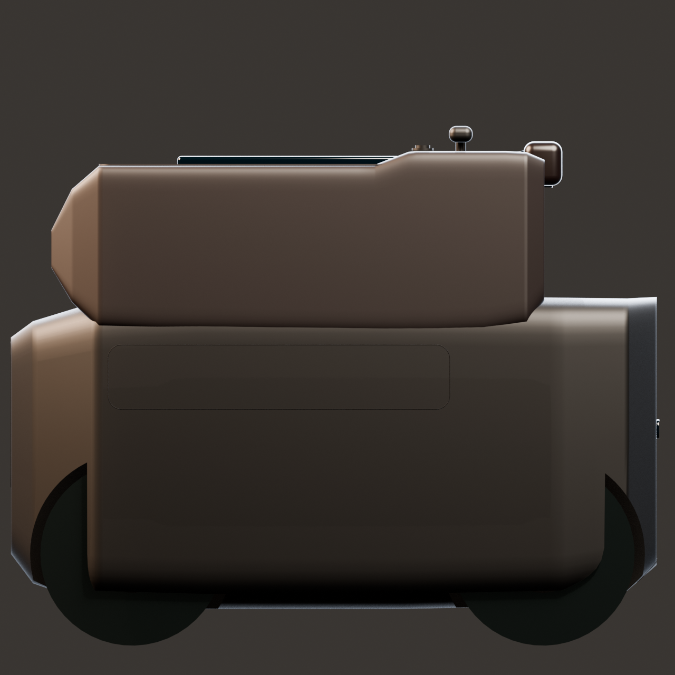
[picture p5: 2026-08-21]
design/e6_final_exterior/v11_v8_blender_exterior_restart_20260721/renders/final/r14/follow/07_follow_right.png

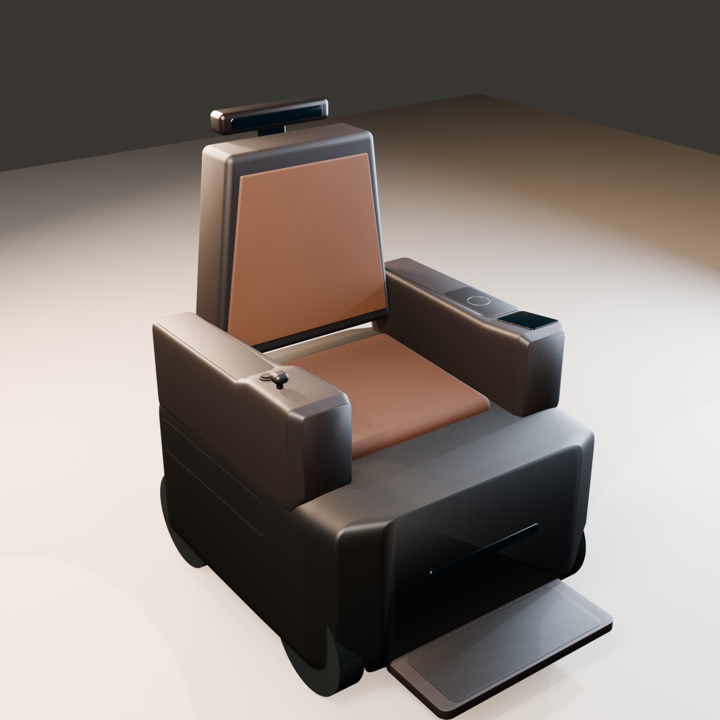
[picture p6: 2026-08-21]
design/e6_final_exterior/v11_v8_blender_exterior_restart_20260721/renders/final/r14/ride/02_ride_front_high.png

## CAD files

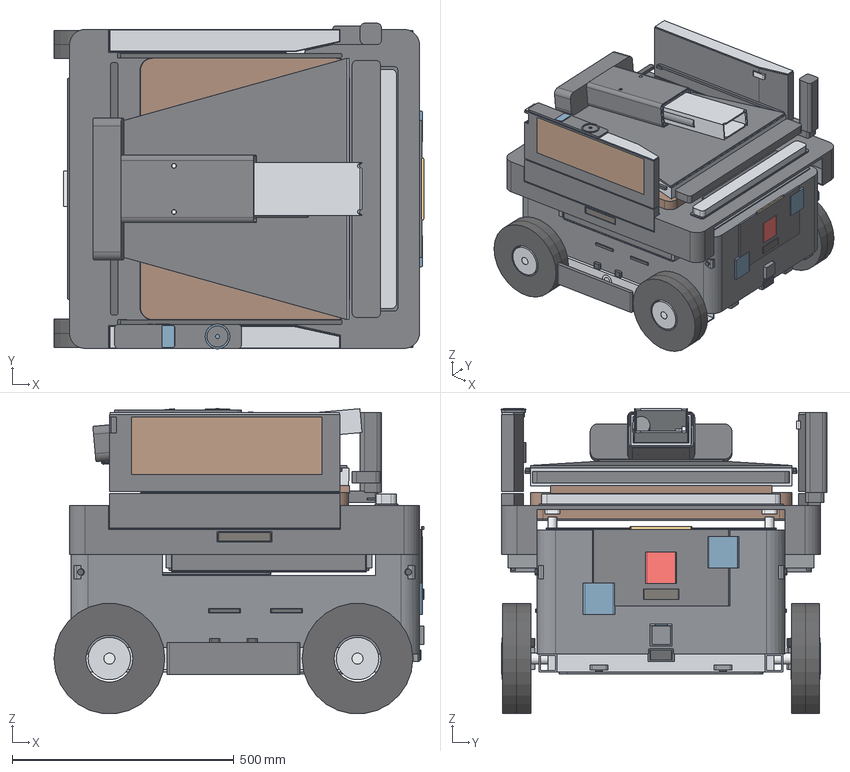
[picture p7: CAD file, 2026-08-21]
design/e6_final_exterior/step_anchored_v2/class_a_cad/controlled_source_e6_dfr4/workcore_e6_dfr4_follow.step
835.0 x 734.8 x 688.6 mm
chassis_rail_left
chassis_rail_right
chassis_crossmember_1
chassis_crossmember_2
chassis_crossmember_3
tyre_front_left
hub_front_left
axle_front_left
tyre_front_right
hub_front_right
axle_front_right
tyre_rear_left
hub_rear_left
axle_rear_left
tyre_rear_right
hub_rear_right
axle_rear_right
suspension_rocker_left
suspension_centre_pivot_left
suspension_elastomer_stop_left_-42
suspension_elastomer_stop_left_+42
wheel_arch_side_fairing_left
suspension_rocker_right
suspension_centre_pivot_right
suspension_elastomer_stop_right_-42
suspension_elastomer_stop_right_+42
wheel_arch_side_fairing_right
battery_lfp_16s30ah_1p536kwh
compute_core_cartridge
encrypted_data_vault
communications_5g_wifi_uwb_module
power_distribution_unit
drive_imu_controller
safety_backup_battery_24v60wh
battery_safety_cassette
battery_pressure_vent_duct
occupant_energy_firewall
battery_compartment_temperature_sensor_-150
battery_compartment_temperature_sensor_170
follow_front_tof_left_module
follow_front_tof_left_window
follow_front_tof_right_module
follow_front_tof_right_window
follow_leg_scanner_module
follow_leg_scanner_window
follow_rear_tof_module
follow_rear_tof_window
follow_side_ultrasonic_module_front_left
follow_side_ultrasonic_face_front_left
follow_side_ultrasonic_module_front_right
follow_side_ultrasonic_face_front_right
follow_side_ultrasonic_module_rear_left
follow_side_ultrasonic_face_rear_left
follow_side_ultrasonic_module_rear_right
follow_side_ultrasonic_face_rear_right
follow_uwb_side_module_left
follow_uwb_side_radome_left
follow_uwb_side_module_right
follow_uwb_side_radome_right
follow_uwb_rear_module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

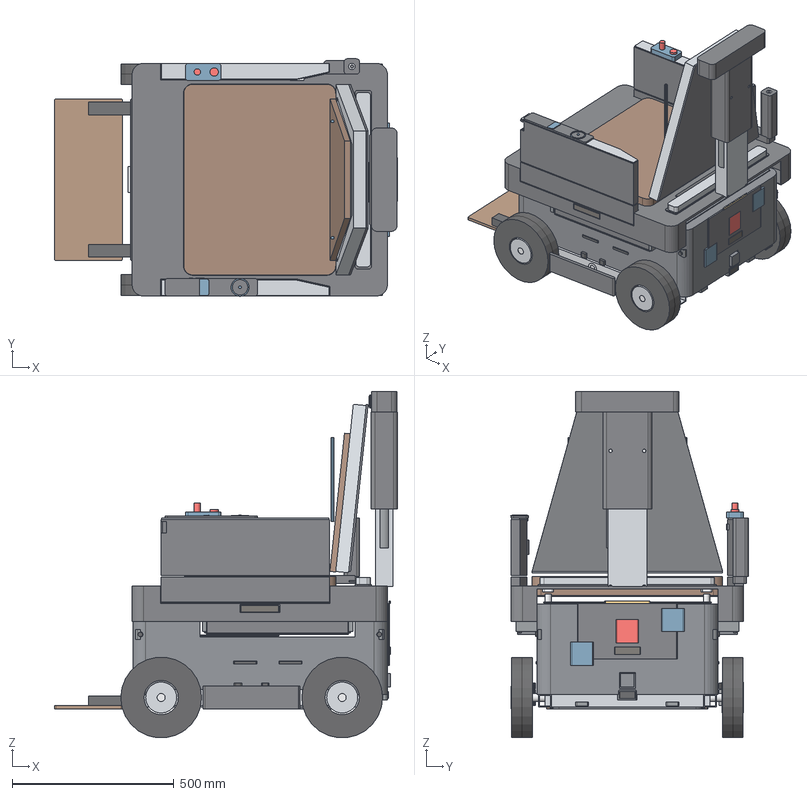
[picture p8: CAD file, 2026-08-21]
design/e6_final_exterior/step_anchored_v2/class_a_cad/controlled_source_e6_dfr5/workcore_e6_dfr5_ride.step
1061.0 x 734.8 x 1071.1 mm
chassis_rail_left
chassis_rail_right
chassis_crossmember_1
chassis_crossmember_2
chassis_crossmember_3
tyre_front_left
hub_front_left
axle_front_left
tyre_front_right
hub_front_right
axle_front_right
tyre_rear_left
hub_rear_left
axle_rear_left
tyre_rear_right
hub_rear_right
axle_rear_right
suspension_rocker_left
suspension_centre_pivot_left
suspension_elastomer_stop_left_-42
suspension_elastomer_stop_left_+42
wheel_arch_side_fairing_left
suspension_rocker_right
suspension_centre_pivot_right
suspension_elastomer_stop_right_-42
suspension_elastomer_stop_right_+42
wheel_arch_side_fairing_right
battery_lfp_16s30ah_1p536kwh
compute_core_cartridge
encrypted_data_vault
communications_5g_wifi_uwb_module
power_distribution_unit
drive_imu_controller
safety_backup_battery_24v60wh
battery_safety_cassette
battery_pressure_vent_duct
occupant_energy_firewall
battery_compartment_temperature_sensor_-150
battery_compartment_temperature_sensor_170
follow_front_tof_left_module
follow_front_tof_left_window
follow_front_tof_right_module
follow_front_tof_right_window
follow_leg_scanner_module
follow_leg_scanner_window
follow_rear_tof_module
follow_rear_tof_window
follow_side_ultrasonic_module_front_left
follow_side_ultrasonic_face_front_left
follow_side_ultrasonic_module_front_right
follow_side_ultrasonic_face_front_right
follow_side_ultrasonic_module_rear_left
follow_side_ultrasonic_face_rear_left
follow_side_ultrasonic_module_rear_right
follow_side_ultrasonic_face_rear_right
follow_uwb_side_module_left
follow_uwb_side_radome_left
follow_uwb_side_module_right
follow_uwb_side_radome_right
follow_uwb_rear_module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

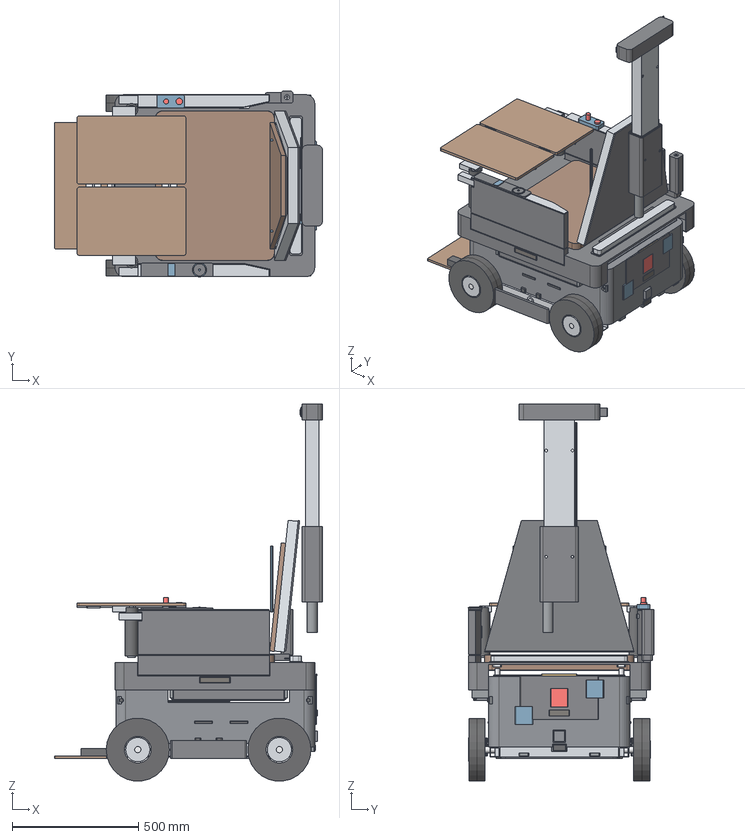
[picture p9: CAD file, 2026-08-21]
design/e6_final_exterior/step_anchored_v2/class_a_cad/controlled_source_e6_dfr5/workcore_e6_dfr5_focus_footrest_open.step
1061.0 x 734.8 x 1491.1 mm
chassis_rail_left
chassis_rail_right
chassis_crossmember_1
chassis_crossmember_2
chassis_crossmember_3
tyre_front_left
hub_front_left
axle_front_left
tyre_front_right
hub_front_right
axle_front_right
tyre_rear_left
hub_rear_left
axle_rear_left
tyre_rear_right
hub_rear_right
axle_rear_right
suspension_rocker_left
suspension_centre_pivot_left
suspension_elastomer_stop_left_-42
suspension_elastomer_stop_left_+42
wheel_arch_side_fairing_left
suspension_rocker_right
suspension_centre_pivot_right
suspension_elastomer_stop_right_-42
suspension_elastomer_stop_right_+42
wheel_arch_side_fairing_right
battery_lfp_16s30ah_1p536kwh
compute_core_cartridge
encrypted_data_vault
communications_5g_wifi_uwb_module
power_distribution_unit
drive_imu_controller
safety_backup_battery_24v60wh
battery_safety_cassette
battery_pressure_vent_duct
occupant_energy_firewall
battery_compartment_temperature_sensor_-150
battery_compartment_temperature_sensor_170
follow_front_tof_left_module
follow_front_tof_left_window
follow_front_tof_right_module
follow_front_tof_right_window
follow_leg_scanner_module
follow_leg_scanner_window
follow_rear_tof_module
follow_rear_tof_window
follow_side_ultrasonic_module_front_left
follow_side_ultrasonic_face_front_left
follow_side_ultrasonic_module_front_right
follow_side_ultrasonic_face_front_right
follow_side_ultrasonic_module_rear_left
follow_side_ultrasonic_face_rear_left
follow_side_ultrasonic_module_rear_right
follow_side_ultrasonic_face_rear_right
follow_uwb_side_module_left
follow_uwb_side_radome_left
follow_uwb_side_module_right
follow_uwb_side_radome_right
follow_uwb_rear_module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

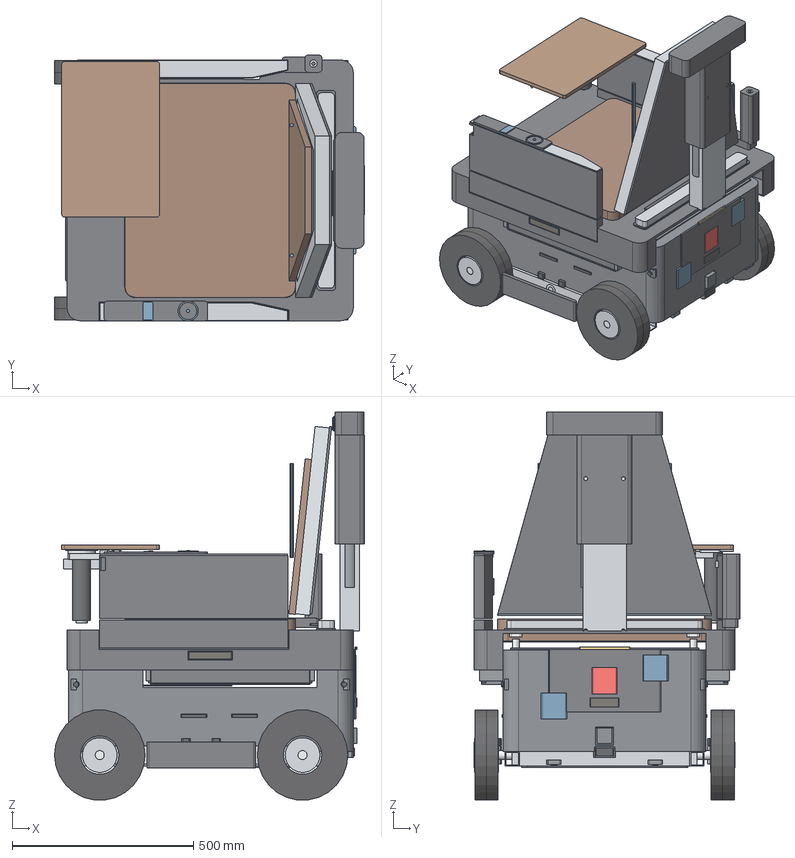
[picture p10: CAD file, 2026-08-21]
design/e6_final_exterior/step_anchored_v2/class_a_cad/controlled_source_e6_dfr5/workcore_e6_dfr5_cafe.step
856.0 x 734.8 x 1071.1 mm
chassis_rail_left
chassis_rail_right
chassis_crossmember_1
chassis_crossmember_2
chassis_crossmember_3
tyre_front_left
hub_front_left
axle_front_left
tyre_front_right
hub_front_right
axle_front_right
tyre_rear_left
hub_rear_left
axle_rear_left
tyre_rear_right
hub_rear_right
axle_rear_right
suspension_rocker_left
suspension_centre_pivot_left
suspension_elastomer_stop_left_-42
suspension_elastomer_stop_left_+42
wheel_arch_side_fairing_left
suspension_rocker_right
suspension_centre_pivot_right
suspension_elastomer_stop_right_-42
suspension_elastomer_stop_right_+42
wheel_arch_side_fairing_right
battery_lfp_16s30ah_1p536kwh
compute_core_cartridge
encrypted_data_vault
communications_5g_wifi_uwb_module
power_distribution_unit
drive_imu_controller
safety_backup_battery_24v60wh
battery_safety_cassette
battery_pressure_vent_duct
occupant_energy_firewall
battery_compartment_temperature_sensor_-150
battery_compartment_temperature_sensor_170
follow_front_tof_left_module
follow_front_tof_left_window
follow_front_tof_right_module
follow_front_tof_right_window
follow_leg_scanner_module
follow_leg_scanner_window
follow_rear_tof_module
follow_rear_tof_window
follow_side_ultrasonic_module_front_left
follow_side_ultrasonic_face_front_left
follow_side_ultrasonic_module_front_right
follow_side_ultrasonic_face_front_right
follow_side_ultrasonic_module_rear_left
follow_side_ultrasonic_face_rear_left
follow_side_ultrasonic_module_rear_right
follow_side_ultrasonic_face_rear_right
follow_uwb_side_module_left
follow_uwb_side_radome_left
follow_uwb_side_module_right
follow_uwb_side_radome_right
follow_uwb_rear_module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

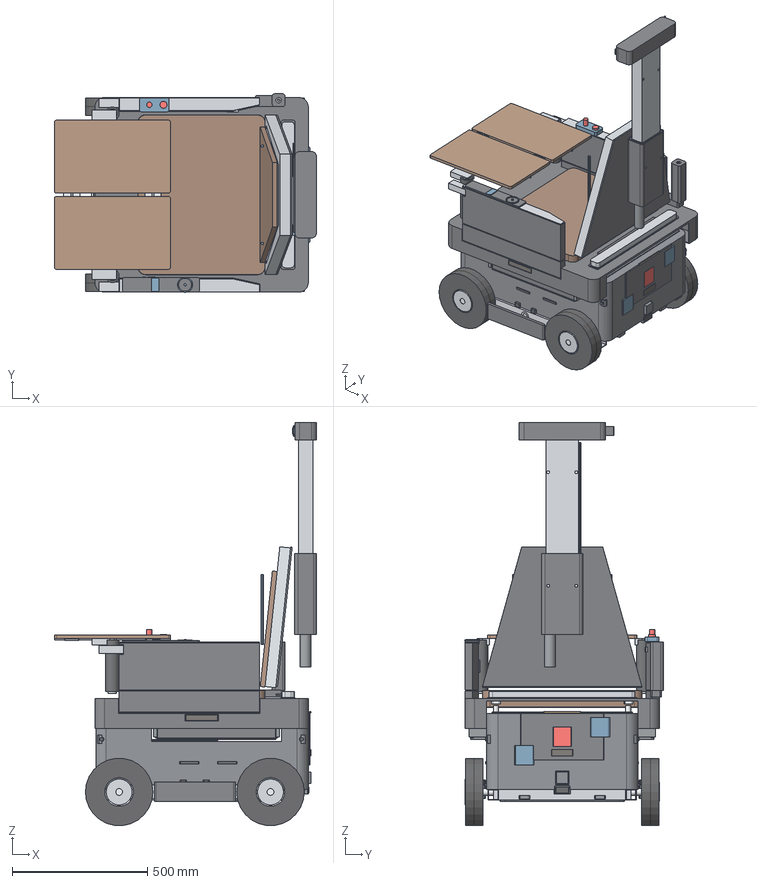
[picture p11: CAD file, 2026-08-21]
design/e6_final_exterior/step_anchored_v2/class_a_cad/controlled_source_e6_dfr5/workcore_e6_dfr5_focus.step
971.0 x 734.8 x 1491.1 mm
chassis_rail_left
chassis_rail_right
chassis_crossmember_1
chassis_crossmember_2
chassis_crossmember_3
tyre_front_left
hub_front_left
axle_front_left
tyre_front_right
hub_front_right
axle_front_right
tyre_rear_left
hub_rear_left
axle_rear_left
tyre_rear_right
hub_rear_right
axle_rear_right
suspension_rocker_left
suspension_centre_pivot_left
suspension_elastomer_stop_left_-42
suspension_elastomer_stop_left_+42
wheel_arch_side_fairing_left
suspension_rocker_right
suspension_centre_pivot_right
suspension_elastomer_stop_right_-42
suspension_elastomer_stop_right_+42
wheel_arch_side_fairing_right
battery_lfp_16s30ah_1p536kwh
compute_core_cartridge
encrypted_data_vault
communications_5g_wifi_uwb_module
power_distribution_unit
drive_imu_controller
safety_backup_battery_24v60wh
battery_safety_cassette
battery_pressure_vent_duct
occupant_energy_firewall
battery_compartment_temperature_sensor_-150
battery_compartment_temperature_sensor_170
follow_front_tof_left_module
follow_front_tof_left_window
follow_front_tof_right_module
follow_front_tof_right_window
follow_leg_scanner_module
follow_leg_scanner_window
follow_rear_tof_module
follow_rear_tof_window
follow_side_ultrasonic_module_front_left
follow_side_ultrasonic_face_front_left
follow_side_ultrasonic_module_front_right
follow_side_ultrasonic_face_front_right
follow_side_ultrasonic_module_rear_left
follow_side_ultrasonic_face_rear_left
follow_side_ultrasonic_module_rear_right
follow_side_ultrasonic_face_rear_right
follow_uwb_side_module_left
follow_uwb_side_radome_left
follow_uwb_side_module_right
follow_uwb_side_radome_right
follow_uwb_rear_module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

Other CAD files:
design/e6_final_exterior/step_anchored_v2/class_a_cad/controlled_source_e6_dfr5/workcore_e6_dfr5_follow.step
design/e6_final_exterior/step_anchored_v2/class_a_cad/controlled_source_e6_dfr5/workcore_e6_dfr5_cafe_footrest_open.step
design/e6_final_exterior/v11_v8_blender_exterior_restart_20260721/blender/e6_v11_v8_locked_reference_master.blend
design/e6_final_exterior/v11_v8_blender_exterior_restart_20260721/blender/states/r14/workcore_e6_v11_cafe_r14.blend
design/e6_final_exterior/v11_v8_blender_exterior_restart_20260721/blender/states/r14/workcore_e6_v11_focus_r14.blend
design/e6_final_exterior/v11_v8_blender_exterior_restart_20260721/blender/states/r14/workcore_e6_v11_follow_r14.blend
design/e6_final_exterior/v11_v8_blender_exterior_restart_20260721/blender/states/r14/workcore_e6_v11_ride_r14.blend

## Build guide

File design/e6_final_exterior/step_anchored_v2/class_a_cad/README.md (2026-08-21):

# WorkCore E6 V8 STEP-anchored exterior skin CAD

本目录不是给受控样机换材质，而是在版本化 `E6-DFR5-A07-SHARED-HINGE` 四态硬点上建立最终外观候选 CAD。DFR5 原则修订源单独位于 `controlled_source_e6_dfr5/`，含四主态与 Café/Focus 可选脚踏展开验证态；它只修正 Follow 中 A07 与 A06 共用 `(160, 0, 515) mm` 铰链，非 Follow 状态与 DFR4 保持字节一致。原 `build/` 中 E6-DFR3 和父版本 DFR4 文件保持只读追溯。脚本对各层输入分别校验 manifest、字节数和 SHA-256；所有新增 STEP、GLB、PNG 与报告只写入本目录的 `release_candidate_v8/`。

## 权威层级

1. `skin_lower.py`、`skin_upper.py`：A01–A10 外覆分件的参数化源；
2. `validate_class_a.py`：几何、状态、净距、功能界面和源文件绑定硬门；
3. `release_candidate_v8/<state>/workcore_e6_class_a_skin_<state>.step`：仅新增外覆件；
4. `release_candidate_v8/<state>/workcore_e6_class_a_<state>_with_read_only_underlay.step`：外覆件与只读受控底图的关联装配；
5. `release_candidate_v8/<state>/*.glb`、`*.png`：设计评审和 QA，不作为尺寸证据；
6. `corrected_renders/` 中的生成图只保留为方向草图，不是 CAD 交付物。

## 构建

在仓库根目录使用项目的 CadQuery 运行环境：

```powershell
$env:PYTHONPATH=(Resolve-Path '.venv\Lib\site-packages').Path
& 'C:\Users\86135\.cache\codex-runtimes\codex-primary-runtime\dependencies\python\python.exe' `
  'design\e6_final_exterior\step_anchored_v2\class_a_cad\build_class_a_skin.py'
```

构建是 fail-closed：先写入 `BUILD_INCOMPLETE`，验证内存几何，导出每个分件 STEP，再从导出的 STEP 重新验证几何、刚性碰撞、GLB 清单和 32 张正式图。只有制品闭包通过、最终 manifest 已原子写入后，脚本才把移除 `BUILD_INCOMPLETE` 作为最后一次发布写操作。不得手工删除该标记；正式完成必须同时满足 manifest 全部数字门为 `PASS`、标记不存在，并以 manifest 只读复核封闭制品集为 `PASS`。

四态共用的 A01 前鼻壳包含永久一体式 front brow 与短上回边，用真实 B-Rep 闭合感知地平线上方脚舱的正常前视、站立及斜上视线；它不是 Follow 专用盖板，也不改变同一梯形靠背的折叠责任。乘员侧脚部通道、感知硬点和 A04 干式分缝由独立门禁保留。

A03 连续轮罩采用不可混用的双区包覆合同：大面积外侧皮只开放 `z=0–32 mm` 的低位接地条，必须通过侧面 `z=20 mm` 开放、`z=55 mm` 闭合探针；仅前后纵向端回因轮胎变形、排水和运动边界保留局部 `z=0–70 mm` 让位，必须通过端部 `z=55 mm` 开放、`z=90 mm` 闭合探针，并在跨轮胎宽度三点和上半部三高度通过 3×3 实体覆盖网格。四个端回还必须各有一件独立月岩体色外层冲击皮：名义厚 `1.0 mm`、与深色结构端回干隙 `0.1 mm`、覆盖 `Y=88.6 mm` 和 `Z=71–314 mm`；深色结构端回本身通过覆盖网格不等于视觉通过。端部让位不得解释为侧面或差速轮整体外露，正/后视不得读成竖向整块黑色轮胎。四轮在 `-10/-5/0/+5/+10°` 的轮罩扫掠净距均为 `15.5 mm`，轮端近齐平硬盖和随盖 EPDM 背衬分别保持 `16.3/15.6 mm`。轮罩名义宽度为 `750.8 mm`、轮端盖局部成品宽度为 `751.0 mm`，均受 `752 mm` 量产设计上限约束。

四态同一右侧 pod、直立摇杆和授权键必须保持相同物理 ID、相同 B-Rep 与同一扶手前端世界坐标，并始终外露；只有 Ride 的锁定态允许牵引。Café/Focus 使用 `140×104×120 mm` 真实操作手包络复核全部 A09 桌板与下部结构，最短干隙不得低于 `5 mm`，不能用“电气禁用”解释桌板遮挡或手无法到达。

左右 A04/A05 连续侧帆以 2 mm RF 透明外皮维持原 V8 的单一平静侧场：UWB 只在内侧做 `0.8 mm` 浅避让，实测外皮必须保留至少 `1.2 mm`，到原硬点 bezel 零干涉且名义干隙 `0.3 mm`；不得开出贯穿的深色长槽。A05 重力排水口仍是独立的 `34×18 mm` 小开口并与侧帆实体零干涉。

A06 根部的固定 A05 壳对 bearing、完整 shaft 和 lock disc 分别执行零公共体积与 `0.6/0.7/0.7 mm` 干隙门禁。Follow/Ride/Café 的 A05 固定壳 B-Rep 相同；Focus 的差异只有在未让位壳确实无法达到 A09 的 `1.5 mm` 干隙、且全部减材局限于三段真实升降级走廊时才成立，因此它是必要包装让位，不是随状态任意改壳。

四态外包络采用“受控 STEP 六面边界 + 独立总尺寸”双锁：纵向 `xmin/xmax` 各自最多允许 `25 mm` Class-A 表皮/回边增量，不能把整机平移来消费另一端余量；同时总长分别受 Follow/Ride/Café/Focus 的 `885/1111/906/1021 mm` 上限约束。横向逐面增量最多 `17 mm`，并继续受 `752 mm` 成品总宽硬上限约束。该规则明确区分“两端各有必要回边”和“单端越界”，不允许用放宽总长掩盖硬点漂移。

A07 的 Focus 位移只作用于同一移动脊柱、冠梁及其功能件：固定套筒不动，延伸捕获为 `150 mm`。移动脊柱通过 `16 mm` 隐藏空心榫进入冠梁套口，具有 `3 mm` 径向装配间隙、`2 mm` 端余隙及 `4 mm` 外观干缝；下置声学网位于结构榫外侧并保持至少 `1.5 mm` 真实干隙，不允许以网片穿入结构件冒充开孔。Ride/Café 保留同一低位感知地平线，Follow 与 A06 共铰折叠，不存在 Focus 临时出现的另一根桅杆。

A10 后服务围框在 A06 连续通道的隐藏视线内设置 `62.4×128.4×72 mm` 真实桅杆通过槽；Ride/Café 的低位移动脊柱对围框实测最小干隙为 `3.642967 mm`，硬门仍为 `3.5 mm`，不使用碰撞白名单。物理隐私快门边框不是贴花：冠梁具有覆盖闭合中心 `Y=-8 mm` 到 Focus 停放中心 `Y=128 mm` 的连续滑架口袋，名义让隙 `0.2 mm`，四态要求零刚体公共体积。

Café 右叶和 Focus 双叶的 A09 根部各使用一件连续收腰空心桌腹；旧 bridge、root fairing、saddle、方盒 belly 及其布尔 service fragment 已从正式发生项退休。三级独立升降件冻结为直壁 XY 定向 squircle 仪器套筒：外截面依次为 `72×70 / 60×58 / 48×46 mm`，内截面为 `66×64 / 54×52 / 40×40 mm`，相邻径向干隙均为 `3.0 mm`，最内级保留 `40 mm` 机构通道；不旋转轴线、不改变 Z 硬点。底部 socket 对第一级的实际最短干隙不得低于 `2.4 mm`；Focus 固定 A05 内缘以受控退让保持 `1.5 mm` 动静干隙，左右桌腹将中央膝部净通道扩大并冻结为 `250 mm`。Focus 独立 root crown、12 mm 桌面中缝和固定 A05 扶手仍保持功能硬点与维修责任。

Focus 每片桌叶的两套机械释放框与拨片位于各自内侧竖直边的 `|Y|=10 mm` 位置，顶面投影为零；到独立 TPE 中缝密封条的名义干隙为 `0.6 mm`，不得恢复跨越中缝的顶置“钢琴铰链”高光。

## 四态输出

- `follow/`：闭合伴随态；只有同一块梯形靠背折叠并直接形成唯一上表面，不增加箱盖、罩壳或第二块遮盖物；A07 固定套筒、单一移动脊柱和同一冠梁先锁定为低态，再与 A06 共用同一铰链折叠。折叠壳只允许对明确标记为非刚性的座垫泡棉形成不超过 `22 mm` 的无乘员名义预压，必须由占用互锁阻止载人折叠，并等待供应商压缩曲线与实体循环验证。
- `ride/`：载人态；脚踏展开、桌面完全收纳、右侧控制权可读。
- `cafe/`：仅右桌展开，左侧保持开放；脚踏默认收纳，双脚可落地。
- `focus/`：同一双桌闭合为工作边界；Ride/Café 已存在的同一 A07 低位感知地平线仅将单一移动脊柱和冠梁上移 420 mm，固定套筒不动；同一右侧控制 pod/直立摇杆/授权键仍固定外露于扶手前端但牵引禁用，桌板不得遮挡；脚踏默认收纳，双脚可落地。

Café/Focus 可以在用户明确请求、产品驻车且扫掠区清空时展开同一 A08 脚踏；这两个可选子状态进入源 CAD 终态、21 点运动扫掠、脚落地路径以及 Class-A 导出前/后静态刚性碰撞验证，但不计入四态 32 张主渲染。正式构建同时逐文件复核这两个子态的 STEP/GLB 与受控 manifest 绑定，不能只凭 manifest 文件存在便继承结论。A08 的平台、左右支撑、左右护套和手动正锁在六态中保持同一物理 ID、材料、B-Rep、定义修订与 `1.890987 kg` 总质量。

每态包含：逐件 STEP、skin-only STEP、带只读底图的关联 STEP、最终评审 GLB、透明底图 QA GLB，以及 hero、QA overlay、front、rear、left、right、top、bottom 八张 1600×1200 正式图。四态共 32 张。`release_candidate_v8/class_a_skin_manifest.json` 记录受控源哈希、完整生成器/设计决策链的构建前后哈希、正式分件数、边界、输出路径、验证门和每个交付文件的 SHA-256；`release_candidate_v8/class_a_validation.json` 保存导出后硬门证据。任何数量或状态结论均以本次正式 manifest 和其引用报告为准，不沿用旧轮次数字。

## 解释边界

这里的结果是可验证、可分件、与受控硬点关联的 **V8 Class-A 外覆方向 CAD / A-surface envelope study**，不是量产 Class-A 曲面放行，也不是结构、安全、法规或量产认证。真正量产放行仍需 Alias/ICEM 级曲率连续性、拔模/分型/壁厚/卡扣与密封工程、供应商 DFM、全运动实体样机、传感透过、清洁老化、人因与法规验证。不能因为数字门通过就跳过这些门。

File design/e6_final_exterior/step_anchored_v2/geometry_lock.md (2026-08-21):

# E6-DFR5-A07-SHARED-HINGE 几何锁定清单

## 状态与坐标

- 坐标：`-X` 为前/脚侧，`+X` 为后，`+Y` 为右，`-Y` 为左，`+Z` 为上。
- Follow、Ride、Café、Focus 分别对应 `controlled_source_e6_dfr5/` 中的版本化受控构型 `follow`、`ride`、`cafe`、`focus`；E6-DFR4 是直接父版，E6-DFR3 是更早只读追溯基线。
- Outdoor Pack 不是第五状态；运输 Stowed 也不等同 Follow。

## 所有纠正图必须保持

### 核心包络与轮组

- 核心体约 `790 × 720 mm`，当前总宽约 `735 mm`。
- Follow 参考包络约 `835 × 735 × 690 mm`；Ride 约 `1061 × 735 × 1072 mm`；Café 默认收纳脚踏时约 `856 × 735 × 1072 mm`；Focus 默认收纳脚踏时约 `971 × 735 × 1492 mm`。
- 四轮均为 `Ø250 × 64 mm`；轮心 `X=-380/+180`、`Y=±326`、`Z=125`，轴距 `560 mm`。
- 固定轴差速/滑移转向语义不变；不得生成汽车式前轮转向、汽车轮拱或长轴距。最终罩壳采用双区锁定：外侧主皮只允许 `z=0–32 mm` 低位接地条（侧面 `z=20 mm` 开放、`z=55 mm` 闭合），仅前后纵向端回允许局部 `z=0–70 mm` 运动/排水让位（端部 `z=55 mm` 开放、`z=90 mm` 闭合）。四个端回必须保留独立月岩体色视觉冲击皮（`1.0 mm` 厚、对结构端回 `0.1 mm` 干隙、`Y=88.6 mm、Z=71–314 mm`），不得让深色结构端回在正/后视中读成完整轮体。不能把端回或 110 mm 轮端维修口误当成半轮/整轮外露许可。

### 座椅、扶手与控制

- 座垫约 `470 × 590 mm`，中心 `X=-75`、坐面约 `Z=500`。
- 靠背宽约 `590 mm`、高 `520 mm`、厚 `80 mm`；铰点约 `X=160, Z=515`，后倾约 `6°`。
- 两条扶手是长结构件，约从 `X=-380` 延伸到 `+140`；不得缩成悬浮小岛。
- 右侧（`Y>0`）保留可拆摇杆/授权键；左侧（`Y<0`）保留 `124 × 50 mm` 显示与 `Ø56 mm` Qi 区。
- 机械急停保留在**左侧内前扶手**，按钮中心约 `X=-294, Y=-320, Z=590`；不能移到右侧、车鼻、屏幕或桌面。

### 脚踏与桌板

- A08 是同一套六 occurrence 机构：`210 × 500 × 10 mm` 平台、左右支撑、左右护套与一件手动正锁；各状态材料、质量、B-Rep 和物理 ID 守恒。
- Follow、Café、Focus 主态默认收纳：平台中心约 `X=-360, Z=147 mm`，支撑/护套竖直收进光学鼻腔，双脚到地面通道不得被占用。
- Ride 默认展开并正锁：平台中心约 `X=-605, Z=95 mm`，上表面约 `Z=100 mm`。Café/Focus 允许同一机构的可选展开子状态，但不进入四态主渲染；必须另过终态、21 点扫掠、夹剪和占用清空门禁。
- 两张桌叶为同一对物理件，每张约 `430 × 270 × 12 mm`，桌面高约 `705 mm`，Focus 中缝目标 `12 mm`。
- Café 只部署右桌：前移清扫、旋转 `90°`、回移约 `80 mm`；终态中心约 `X=-350`，左侧保持开放。
- 桌板必须从对应扶手收纳体积/机构路径出现，不得从虚构侧柱或车身缝中凭空生成。

### A06/A07、传感、服务

- 后中 A07 轴线锁定在 `X=310 mm`；四态使用同一固定套筒、一件完整移动脊柱与同一冠梁，不得出现 `stage_2` 或 `stage_3`。
- Ride/Café 的同一智能梁保持低位、约 `Z=1040 mm`；Focus 只将移动脊柱、冠梁及其功能件升高 `420 mm`，固定套筒不动。Follow 中低态 A07 与 A06 共用 `(160, 0, 515) mm` 铰链随靠背折叠，不能让桅杆只在 Focus 凭空出现。
- Focus 中固定套筒对移动脊柱的轴向捕获不得低于 `150 mm`，固定/移动最短净距不得低于 `5 mm`。移动脊柱以 `16 mm` 隐藏空心榫进入冠梁 `42 × 86 mm` 套口，保留 `3 mm` 径向间隙、`2 mm` 端余隙和 `4 mm` 外观干缝；禁止零距离面接触。
- A06 是具有真实内腔、名义壁厚 `4 mm` 的同一空心梯形靠背壳；根部由四态固定的左右 A04 空心根肩闭合，不得使用状态专用 A06 root cheek。
- 实体隐私片位于智能梁烟熏窗口，不得移到车身侧面。
- 低位导航感知窗、前触边、声学/RF 区、后服务门与恢复路径不得因光滑外壳消失。

## 允许重塑

- lower/upper cosmetic skin；
- wheel-arch / rocker fairing，但不得移动轮组或伪装转向形式；
- armrest shell / lid 的曲面与触感；
- backrest rear cosmetic shell；
- mast shroud / sensor beam bezel；
- 桌面边缘、脚踏表皮、服务门切线；
- CMF、纹理、真实材料边界、少量功能揭边、可制造圆角与曲率连续性。

## 单图否决条件

任一项出现即否决，不进入下一轮：

- 四轮数量、轮径、轮心或轴距明显漂移；
- 核心变成汽车、胶囊舱、轮椅、配送机器人或行李箱；
- 取消长扶手/梯形靠背/脚踏/A07，或让 A07 只在 Focus 凭空出现、退回三级行李拉杆语法、脱离 A06 Follow 共铰关系；
- Café 非右桌部署或左侧不开放；Focus 桌板不是同一对物理件；
- 隐私片、急停、HMI 或服务门位置错误；
- 为“极简”封死传感、散热、排水、拆装或无电释放。

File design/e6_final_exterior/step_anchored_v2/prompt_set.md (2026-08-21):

# STEP Anchored 图像提示词原则

## 模式

- 正式工具链：受控 STEP/GLB → 参数化 Class-A CAD → VTK 物理渲染；32 张发布图必须直接来自同一次受控几何构建。
- ImageGen 仅可用于不进入发布包的早期语义探索，不得重画、替换或“美化修复”正式产品几何，也不得作为 STEP 一致性的证据。
- 每张正式图的几何来源：对应状态的 E6-DFR5-A07-SHARED-HINGE STEP/GLB 与其同构 Class-A 外覆，不以截图近似或文字提示猜测硬点。
- 最高优先级：轮心、总包络、硬点、扫掠、左右接口与状态拓扑；允许在这些边界内新增/替换独立 Class-A cosmetic skin。

## 四态共用不变量

```text
Image 1 is a controlled E6-DFR5 engineering underlay derived from the exact same physical occurrence list as the STEP assembly. Preserve its exact camera, wheel centers and diameters, axle spacing, ground contact, chassis/occupant envelope, functional hardpoints, motion-state topology, long fixed armrests, flat seat, the same hollow trapezoidal folding backrest, A08 footrest, right control pod, left display/Qi/emergency-stop zone, rear-center A07 axis, crowned sensor beam, desk leaves and all required service/sensor openings. A07 is the same fixed sleeve, one-piece moving spine and crowned beam in every state: Ride/Café are low, Follow co-folds on the A06 hinge, and Focus raises only the moving member and beam by 420 mm; never invent stage 2 or stage 3 and never make the mast appear only in Focus. A08 is one invariant six-occurrence physical assembly with one 210 × 500 × 10 mm platform and 1.890987 kg analytical mass; pose may change transforms only, never identity, definition, material, volume or mass. Treat exposed rails, brackets, carriers, actuators, supports and part clutter as inner engineering—not final visible surfaces. Design a small number of removable Class-A exterior shells around them, staying inside controlled overall envelopes and outside all motion, body, view, cooling, drainage and service keep-outs. Enclose every differential wheel with a two-zone C-wrap: the broad outboard side exposes only z=0–32 mm (open at z=20, opaque at z=55), while only the narrow front/rear longitudinal returns retain a local z=0–70 mm motion/drainage relief (open at z=55, opaque at z=90). Each of the four end returns needs a separate 1.0 mm lunar-stone body-colour outer impact skin, dry-gapped 0.1 mm from the dark structural return and spanning Y=88.6 mm and Z=71–314 mm; a dark structural return alone must fail because it reads as a tall exposed wheel in exact front/rear views. Never read either the end relief or the 110 mm service aperture as permission to expose a half or whole wheel.
```

## 外观变更

```text
Develop the final production-intent “Quiet Orbit” appearance on that underlay: fully wrap the lower chassis/frame, long-armrest mechanisms/table bundles, trapezoidal backrest carrier, footrest supports, mast drive and desk under-mechanisms with coherent manufacturable removable outer shells. Retro-futurist through late-1960s precision-instrument restraint; minimal, smooth, premium and mysterious without hiding intent. Warm lunar-stone fine-matte cosmetic shells, deep graphite-brown lower enclosure and functional hardware, smoked-umber real sensor windows only at existing apertures, sparse satin champagne anodized reveals, charcoal removable 3D-knit contact surfaces and espresso anti-fingerprint desk/foot surfaces. Use controlled real seams, TPE seals and replaceable scuff edges. No brand text.
```

## 共同否决项

```text
Do not turn it into a car, capsule, cockpit, wheelchair, mobility scooter, delivery robot, luggage, office chair or a different product. No automotive nose, grille or fenders; no full-width fake black glass; no new wheel arches; no steering wheels; no bucket seat; no short floating arm pods; no shrunken bumper-like footrest; no invented side service door; no moved privacy shutter; no fake side camera; no robot eyes; no RGB; no giant screen; no fins, portholes, decorative vents, exposed cables or impossible floating parts; no text, logo or watermark.
```

## 状态专用锁定

- Follow：同一空心梯形靠背后壳继续作为唯一天气盖；同一低态 A07 与 A06 共铰折叠；A08 脚踏为 `STOWED`；前部凹入踏阶、四轮和现有传感/服务开口保持；不得另造整体车罩。
- Ride：同一 `210 × 500 × 10 mm` A08 平台为 `DEPLOYED_LOCKED`；两条约 `520 mm` 固定长扶手、梯形靠背、右摇杆、左显示/Qi/急停与同一低位 A07 智能梁保持。
- Café：A08 主态为 `STOWED`，双脚可落地；只保留源图中的右桌部署，左侧开放；同一摇杆、pod 与授权键固定外露于右扶手前端且桌板不得遮挡，只撤销牵引授权；桅杆低位；不得改成另一种桌轨迹。显式脚踏展开属于单独可选子态。
- Focus：A08 主态为 `STOWED`，双脚可落地；源图中的同一双桌叶、中心缝保持；A07 仅让 Ride/Café 已存在的同一移动脊柱与冠梁升高 `420 mm`，固定套筒不动；隐私片只在智能梁前脸。显式脚踏展开属于单独可选子态。

正式四主态渲染范围固定为 Follow、Ride、Café、Focus 各 8 张，共 32 张；Café/Focus 的可选脚踏展开子态不得混入或替换这 32 张主态图。

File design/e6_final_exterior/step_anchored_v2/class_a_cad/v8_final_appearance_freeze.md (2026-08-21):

# WorkCore E6 V8 最终外观冻结约束

本文件记录用户在最终渲染收口阶段明确给出的不可回退约束。它约束独立
Class-A 外观研究与渲染。默认不修改 `build/` 中受控 STEP/GLB 输入；若复测
证明存在架构级原则错误，用户后续明确允许修订 STEP，但必须保留原版、另存
版本化修订、记录前后哈希与影响状态，并从几何到正式渲染重跑全部门禁。不得
为了放宽外观包覆、回避碰撞或迎合截图而移动受控硬点。

## 物品特征

- 最终读感必须是完整、平滑、克制而高级的新物品，不得读作轮椅、裸底盘、
  样机框架或机构堆叠。
- 复古科幻来自比例、连续体量、精密分缝和被克制隐藏的能力，不来自装饰件、
  假灯带、假屏幕或无功能黑缝。
- 正常使用视角不得看到裸露连杆、导杆、铰链、框架、线束或开放设备腔。

## 本轮明确冻结

1. **Follow 上表面**：随行态只由同一块梯形靠背折叠形成；不得再叠加箱盖、
   大罩壳或其他表面遮盖物。桌面与观察机构必须收进既有体量内部。同一硬壳
   只允许对明确的非刚性座垫泡棉形成不超过 `22 mm` 的无乘员名义预压；
   必须有占用互锁，供应商压缩/永久变形曲线和实体循环未通过前不得据此宣称
   物理放行。
2. **差速轮**：四个差速轮不得整圈、整面外露。上半圈和内侧机构应被连续
   轮眉/轮罩吸收。大面积外侧皮只保留 `z=0–32 mm` 低位接地条，侧面探针
   必须证明 `z=20 mm` 开放、`z=55 mm` 闭合；仅前后纵向端回为必要运动、
   排水边界保留局部 `z=0–70 mm` 让位，端部探针必须证明 `z=55 mm` 开放、
   `z=90 mm` 闭合。端部让位和 110 mm 轮端维修口均不得被解释为侧面或
   差速轮整体外露；元数据必须为 `tyre_lower_contact_band_visible=True` 且
   `tyre_lower_contact_half_visible=False`。端回覆盖还必须由四件独立
   月岩体色外层冲击皮完成：每件名义厚
   `1.0 mm`、与深色结构端回干隙 `0.1 mm`、覆盖 `Y=88.6 mm`、
   `Z=71–314 mm`。深色结构端回本身通过实体探针不得替代这层视觉包覆，
   正视和后视均不得形成竖向整块深色轮体读感。四轮在 `-10/-5/0/+5/+10°`
   的名义扫掠净距均不得低于 `15.5 mm`；为保留 `1.9 mm` 壳壁，轮罩名义
   外宽冻结为 `750.8 mm`；轮端盖局部成品外宽为 `751.0 mm`，量产设计上限
   为 `752 mm`。维修盖及其随盖拆卸 EPDM 背衬也必须分别满足至少
   `15.5 mm` 的扫掠净距，不能只检查外轮罩。
3. **扶手**：当前版本不考虑侧向打开扶手。左右扶手均为固定式连续壳体，
   不保留右侧翻开铰链、连杆、释放拨片或相应运动分缝。
4. **机构包覆**：A01 前脚舱必须以四态永久存在、与前鼻壳一体的视线冠板
   闭合正常站立及斜上视角，同时保留乘员侧脚部通道；下层开放腔、脚踏支撑
   与铰链、桌板下方支撑、A07 固定套筒与单件移动脊柱均须以真实可制造的内衬、随动
   护罩、套筒或端盖闭合。不得用状态专用盖板或改变相机角度掩盖开放腔。
   Café 右桌叶与 Focus 左右桌叶的根部各自只能由一件连续收腰空心桌腹承担
   外观包覆；旧 bridge、root fairing、saddle、方盒 belly 及其 service
   segment/return 布尔残段不得进入正式 BOM 或渲染。
5. **A09 桌机构语法**：Café 右侧与 Focus 左右侧的三级桌腿必须保持三个
   独立实体，但外观统一为直壁 XY 定向 squircle 仪器套筒；外截面依次冻结为
   `72×70 / 60×58 / 48×46 mm`，内截面为
   `66×64 / 54×52 / 40×40 mm`，相邻径向干隙均为 `3.0 mm`，最内级
   机构通道不得小于 `40 mm`。不得改变轴线、Z 硬点或增加 yaw。底部 socket
   到第一级的实际干隙不得小于 `2.4 mm`；Focus 移动级到固定 A05 的最小
   干隙不得小于 `1.5 mm`，中央桌腹膝部净通道冻结为 `250 mm`。不得恢复
   软盒堆叠、裸杆、单根假实心柱或以收窄通道换取激进造型。
6. **A06/A07 物理架构**：四态必须保留同一 A07 固定套筒、一件完整移动脊柱
   和同一冠梁；不得出现 `stage_2` 或 `stage_3`。Ride/Café 已有同一低位感知
   地平线，Focus 只把移动脊柱、冠梁及其功能件受控升高 `420 mm`，固定套筒
   不动；Follow 中低态 A07 与同一 A06 铰链随靠背折叠，不得让桅杆在 Focus
   凭空出现。A06 必须是有真实内腔、名义壁厚 `4 mm` 的单一空心壳；靠背根部
   由四态固定的左右 A04 空心根肩闭合，不得恢复按状态复制的 A06 root cheek。
   Focus 中固定套筒对移动脊柱的轴向捕获不得少于 `150 mm`；移动脊柱必须以
   `16 mm` 隐藏空心榫插入冠梁套口，并保留 `3 mm` 径向装配间隙、`2 mm`
   端余隙与 `4 mm` 外观干缝，不得恢复零距离面接触。下置麦克风声学网必须
   位于结构榫外侧并保持至少 `1.5 mm` 干隙，不得与移动脊柱实体穿模。A10
   后服务围框必须具有 `62.4×128.4×72 mm` 的真实隐藏通过槽，使 Ride/Café
   低位移动脊柱保持至少 `3.5 mm` 刚体干隙；不得以碰撞白名单替代开槽。
   物理隐私快门边框必须在冠梁内拥有从闭合位到 Focus 停放位的连续滑架口袋，
   名义让隙 `0.2 mm`，四态均要求与冠梁零公共体积。
7. **安全可读性**：包覆不得隐藏轮胎接地、低位感知地平线、急停、驻车状态、
   隐私状态、手动救援和必要维修边界。
8. **脚踏状态与物理守恒**：四态主输出中 Follow、Café、Focus 默认收纳同一
   A08 脚踏，Ride 默认展开并正锁；Café/Focus 可选打开，但只作为额外验证
   子状态。平台、左右支撑、左右护套与手动正锁必须保持同一物理 occurrence、
   材料、B-Rep、定义修订与质量；平台/支撑只允许受控刚体姿态变化，车身侧
   手动正锁及其完成态拨片外罩在四态保持零位移、同一 B-Rep，并由 A01 永久
   下侧释放通道接纳。不得再用收纳小薄板和展开大总成两套模型冒充同一产品。
   Café/Focus 收纳态必须保留双脚落地通道，
   可选展开必须通过终态和至少 0/25/50/75/100% 扫掠，本版实际采用 21 点。
9. **外包络双锁**：最终皮肤相对哈希绑定 DFR5 STEP 的纵向 `xmin/xmax`
   每一面最多各增长 `25 mm`，横向 `ymin/ymax` 每一面最多各增长 `17 mm`；
   任何单面超限都必须失败，不能用另一侧未使用余量抵消。与此同时，
   Follow/Ride/Café/Focus 总长分别不得超过
   `885/1111/906/1021 mm`，成品总宽不得超过 `752 mm`；逐面 allowance
   与总尺寸上限必须同时通过。
10. **Focus 中缝锁件**：左右叶片各自的两套机械释放框与拨片必须安装在
    内侧竖直边，中心绝对 Y 坐标为 `10 mm`，顶面投影为零；它们与各自
    TPE 中缝密封条的名义干隙不得小于 `0.6 mm`，不得恢复跨缝顶置铰链语言。
11. **右侧控制恒定位置**：同一右侧控制 pod、直立摇杆与授权键在 Follow、
    Ride、Café、Focus 四态都必须位于扶手顶盖前端同一受控坐标并始终外露；
    不得收入盖下、移到桌板后方、按状态后移或折平。只有 Ride 允许牵引授权，
    其余三态通过安全状态禁用行驶而不是隐藏控制。顶盖外翻取桌时控制岛随同
    一顶盖运动且不得拆下；顶盖闭合、双锁确认后桌板才可展开。Café/Focus
    桌板、桌腹、锁件及手臂扫掠必须避开控制岛和真实手部可达包络；四态三件
    控制 B-Rep、物理 ID 和世界坐标必须一致，Café/Focus 的 `140×104×120 mm`
    椭圆柱操作手包络到全部 A09 实体的最短干隙不得低于 `5 mm`。
12. **连续侧帆的隐藏 UWB 让位**：左右 2 mm RF 透明侧帆不得开出外观长槽；
    原 UWB 硬点只允许 `0.8 mm` 内侧浅避让，外表皮实测剩余厚度不得低于
    `1.2 mm`，到可换 UWB bezel 保持零干涉和名义 `0.3 mm` 干隙。唯一小型
    贯穿开口是独立的 `34×18 mm` 重力排水口，侧帆与其实体 bezel 零干涉。
13. **A05/A06 根部让位**：每侧固定 A05 壳必须保持一个有效实体，到 A06
    bearing/完整 shaft/lock disc 的公共体积均为零；bearing 名义干隙 `0.6 mm`，
    shaft 与 lock disc 名义干隙 `0.7 mm`。Follow/Ride/Café 的固定 A05 壳
    B-Rep 必须相同；Focus 只允许为真实双侧 A09 升降级的 `1.5 mm` 干隙局部
    减材，不得增加材料或在受控让位走廊之外改变外皮。

## 渲染放行

- 四状态各包含 hero、QA overlay、front、rear、left、right、top、bottom，
  共 32 张 1600×1200 图。
- 不得有裁切、空白、假彩、近黑底视图、视角错配或临时探针图。
- 所有正式图必须由本目录生成的 STEP 锚定 GLB 渲染，并在导出后门禁通过后
  才能移除 `BUILD_INCOMPLETE`。

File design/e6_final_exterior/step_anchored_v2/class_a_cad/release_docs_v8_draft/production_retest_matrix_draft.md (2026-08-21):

# WorkCore E6 V8 工业化复测矩阵（草案）

文档状态：`V8 数字 CAD 候选复测矩阵源；正式数字状态以同版 manifest 与报告为准`

量产放行状态：`NOT CERTIFIED / BLOCKED（静态数字 CAD 证据不构成量产认证）`

## 1. 证据等级与判定规则

| 等级 | 证据定义 | 当前可支持的结论 |
|---|---|---|
| L0 | 名称、元数据、责任声明 | 只能证明记录存在，不能证明几何或性能 |
| L1 | 静态 B-Rep、哈希、导出回读、数字清单 | 可证明指定姿态的数字几何和配置完整性 |
| L2 | 运动学/公差/热/结构/RF 数字仿真 | 可支持工程设计收敛，不能替代实体试验 |
| L3 | 功能台架、材料试片、局部总成样机 | 可验证局部物理性能 |
| L4 | 全尺寸工程样机与真实场景试验 | 可支持 DVT/PVT 决策 |
| L5 | 第三方认证、量产过程能力和签署记录 | 才可进入法规与量产放行 |

V8 只有在正式 manifest 引用的 pre-export、post-export、post-STEP、碰撞、GLB、raster 与制品闭包报告全部为 `PASS`，并且 `BUILD_INCOMPLETE` 不存在时，才能把对应结果记为 L1 数字证据。L2 至 L5 的完成结果均为 `TBD`。

判定规则：任何硬门失败即停止升级；没有报告、原始数据、样本编号、环境条件和责任人签署的项目一律记为 `TBD`，不得记为通过。

## 2. 复测触发规则

以下变化至少触发对应行及其下游行重新测试：

- 受控 STEP、姿态或硬点变化：重跑全部数字门、运动包络、结构、热、RF、人因与法规影响分析；
- 外壳面、分件线、壁厚或材料变化：重跑 Class-A、DFM、公差、热、RF、环境、清洁与 CMF；
- A05/A07/A08/A09/A10 机构或开口变化：重跑碰撞、夹剪点、排水、无电释放、误用、疲劳和服务测试；
- A08 默认姿态、可选子态、物理 occurrence、平台定义或质量变化：除完整四态数字门外，重跑 Café/Focus 可选展开端点、全行程扫掠、足部落地路径、配置质量和 32 图范围审计；
- 传感窗、涂层、金属装饰或紧固件变化：重跑光学/RF/EMC、环境老化与可维护性；
- 软件状态机、灯声屏时序或权限变化：重跑四态识别、故障退化、隐私、低电/离线和真实中断恢复；
- 供应商、工艺、模具穴号或材料批次变化：重跑首件、尺寸能力、CMF、环境和可靠性抽检。

## 3. 阶段 A：配置与数字几何

| ID | 复测问题 | 方法与最小证据 | 判定门槛 | 当前结果 |
|---|---|---|---|---|
| A-01 | 四态受控 STEP 是否未变 | `qa/input_pin_report.json`＋manifest 构建前后字节数/SHA-256；与冻结基线逐项比较 | 四态构建前后完全一致 | `以正式报告为准；必须 PASS` |
| A-02 | 四态是否由同一物品语法生成 | source disposition ledger、occurrence ID、零件责任与状态差异清单 | 0 unknown、0 duplicate、每个受控 occurrence 有明确责任；不得出现无来源的第二套状态专用品 | `以正式 ledger 与 manifest 为准；跨态责任的人为签署仍 TBD` |
| A-03 | 每个外观件是否为单实体 | manifest 记录的全部 `SkinPart`；pre-export、STEP 回读和 post-export B-Rep 拓扑复核 | 1 个有效正体积实体/件；实际件数只读正式 manifest | `以正式报告为准；必须 PASS` |
| A-04 | 检查报告是否可审计 | pre/post 检查 ID gate；唯一 check ID＋非空 `evidence_kind` | 100% 满足；实际检查数只读正式报告 | `以正式报告为准；必须 PASS` |
| A-05 | 导出 STEP 是否改变几何 | 每件导出后重新导入；比较实体数、体积、面积、边界和拓扑签名 | 全部满足 gate 中预先冻结的数值容差，无未解释漂移 | `以 qa/exported_part_step_reload_gate.json 为准；必须 PASS` |
| A-06 | GLB 单位与清单是否正确 | 读取单位、节点/几何名、世界边界并与 STEP 对照 | 单位为 m；节点、几何和边界满足 gate 中预先冻结的容差 | `以 qa/glb_units_inventory_gate.json 为准；必须 PASS` |
| A-07 | 最终制品集是否封闭 | manifest 逐文件哈希；检查缺失、额外和哈希差异；marker 状态 | 0 缺失、0 额外、0 哈希差异，artifact closure PASS 且 `BUILD_INCOMPLETE` 不存在 | `以正式 manifest 与发布后只读闭包复核为准；两者缺一不可` |
| A-08 | 四态联合边界是否锁定 | 受控 STEP＋最终皮肤联合包围盒；分别比较 `xmin/xmax/ymin/ymax/zmin/zmax`，再独立比较总长/总宽/总高 | 纵向两端逐面增量均 `<=25 mm`，横向两侧逐面增量均 `<=17 mm`，任何单端超限不得用另一端余量抵消；Follow/Ride/Café/Focus 总长分别 `<=885/1111/906/1021 mm`，总宽 `<=752 mm`，逐面与总尺寸双锁均通过 | `以正式 pre/post-STEP 几何报告为准；必须 PASS` |
| A-09 | 非豁免刚性件是否零交叠 | 全状态、全零件对 pre-export 与 post-STEP B-Rep common volume | 0.1 mm³ 硬门；1e-6 mm³ 数值残差；四态硬碰撞均为 0；无未解释白名单 | `以正式八份四态碰撞报告为准；必须 PASS` |
| A-10 | 软界面豁免是否真实 | TPE/密封件材料、压缩曲线、接触责任和供应商数据 | 每项均有物理依据 | `TBD` |
| A-11 | E6-DFR5 A08 是否仍是一套姿态不变的物理总成 | 对 Follow/Ride/Café/Focus 及 Café/Focus 显式展开子态核对 47 个 occurrence ID、刚性 B-Rep、体积/拓扑签名和刚体变换；另行核对材料、紧固件、线束、EBOM 与质量 | 所有姿态均为同一 47 件生产意图库存；Follow/Café/Focus=`STOWED`，Ride=`DEPLOYED_LOCKED`；可选子态不得进入 32 图；旧六件/`1.890987 kg` 不得继续作为量产结论 | `数字几何由正式 gate 复核；材料、质量与首件仍 TBD` |
| A-12 | A06 是否为真实空心壳且靠背根部责任是否跨态固定 | 对 A06 做空腔、左右壁厚、单实体/有效性探针；四态逐件核对左右 A04 固定根肩的 occurrence、B-Rep、位置、A06 净距与旧 A06 state cheek 禁用清单；单独量化 Follow 硬壳—非刚性座垫预压 | A06 存在真实内部空腔且名义壁厚 `4 mm`；每态恰好两件同一固定 A04 根肩；不得存在 A06 状态专用根部 cheek；根肩与 A06 共体积为 0、最小净距 `>=4 mm`；只有无乘员 Follow 可出现座垫名义预压且深度 `<=22 mm`、公共体积 `<=70,000 mm³`，Ride/Café/Focus 必须为 0，并要求占用互锁、供应商压缩曲线与实体循环 | `静态 L1 以正式 pre/post-STEP 报告为准；泡棉、互锁和实体寿命 TBD` |

## 4. 阶段 B：外观与 Class-A

| ID | 复测问题 | 方法与最小证据 | 判定门槛 | 当前结果 |
|---|---|---|---|---|
| B-01 | 四态是否仍读作同一物品 | 同一次构建的四主态 4×8 正式图、轮廓叠加、无标注 5 秒评审；另审计 Café/Focus 可选脚踏展开图未混入 | raster 必须 32/32 PASS；四主态默认脚踏姿态正确；可选子态 0 张混入；同一物品识别门槛：`TBD` | `raster 以正式报告为准；人工识别仍 TBD` |
| B-02 | Follow 是否低、闭合且不露机构 | 1:1 前后左右、顶/底视、透明 QA 叠图和实体样机；确认只有同一梯形靠背折叠；A07 先保持低态并与 A06 共用同一铰链随行折叠，不另造收纳盖或状态专用品 | 正常观察位不得看到指定内部件；不得出现额外盖板；A06/A07 共铰链和跨态物理守恒必须通过正式 gate；观察位定义：`TBD` | `静态 L1 以正式几何与 raster 报告为准；实体结果 TBD` |
| B-03 | Ride 是否避免医疗椅读感 | 无品类提示用户测试；记录首词、主体归属和坐入意图；核对 A08 已展开正锁但机构未裸露 | 样本量与阈值：`TBD` | `TBD` |
| B-04 | Café 是否明确单侧开放 | 5 秒接近侧、驻车和桌边界判断；主态核对 A08 收纳且双脚可落地 | 样本量与阈值：`TBD` | `TBD` |
| B-05 | Focus 是否不是“大桌版 Ride” | 对照 Ride/Café/Focus 轮廓；核对 Focus 主态 A08 收纳、双脚可落地、双桌、外露 A07 工作脊柱以及同一右侧 pod/joystick/key 仍固定外露但牵引禁用；再做任务叙述测试 | 数字状态差异满足正式 gate；桌板不得遮挡控制及操作手包络；样本量与识别阈值：`TBD` | `静态 L1 以正式几何/raster 报告为准；用户结果 TBD` |
| B-06 | 主外表面高光是否连续 | 斑马纹、反射线、曲率梳、环境高光动画 | G0/G1/G2 分区与数值阈值：`TBD` | `TBD` |
| B-07 | 面差、缝隙和分件是否一致 | 1:1 数模＋实体 CMM/塞规/面差规 | 分区公差：`TBD` | `TBD` |
| B-08 | 轮端和运动意图是否可读 | 核对 A03 完整胎宽 C-wrap、前后轴平面端回、四件月岩体色视觉冲击皮、内侧下翻、近齐平维修盖与随盖 EPDM 背衬；每只轮分别做侧面 `z=20 mm` 开放/`z=55 mm` 闭合与端部 `z=55 mm` 开放/`z=90 mm` 闭合探针，并分别对结构端回和体色外皮执行跨轮胎宽度三点×上半部三高度的 3×3 实体覆盖探针；逐轮对轮罩、盖和背衬执行 `-10/-5/0/+5/+10°` 扫掠并核对成品外宽，再做 2 m/5 m 正视、后视及移动观察 | `tyre_lower_contact_band_visible=True`、`tyre_lower_contact_half_visible=False`；外侧主皮 `z=0–32 mm`、端回局部让位 `z=0–70 mm`，四个基准探针和两层 3×3 覆盖网格全部通过；体色外皮每件厚 `1.0 mm`、对结构端回干隙 `0.1 mm`、覆盖 `Y=88.6 mm、Z=71–314 mm`；轮罩/盖/背衬五点最小净距均 `>=15.5 mm`；轮罩 `750.8 mm`、局部成品 `751.0 mm`、设计上限 `752 mm`；深色结构端回、端回让位与 110 mm 维修口均不得被误算为视觉包覆或半轮/整轮外露许可；人因门槛：`TBD` | `静态 L1 以正式几何/raster 报告为准；连续扫掠与人因 TBD` |
| B-09 | 深色窗是否被误判为屏幕 | A05/A07/A01 黑面面积量化＋无讲解测试 | 误判率：`TBD` | `静态形态以正式几何/raster 报告为准；用户结果 TBD` |
| B-10 | 实体 CMF 是否达到高级感且可维护 | 三套 1:1 材料样板；自然光/室内光/污损后评审 | 色差、光泽、纹理阈值：`TBD` | `TBD` |
| B-11 | A01 前脚舱是否在四态正常视角闭合 | 同版四态 hero/front/top/左右视、QA 叠图与 B-Rep 探针；核对永久 front brow/upper return 与乘员侧脚部通道 | 四态同一 A01 责任；前/站立/斜上视线不得看到内部构件；不得用状态盖板或视角规避；数字壁厚、零交叠、干缝与脚部通道满足正式 gate | `静态 L1 以正式几何、碰撞与 raster 报告为准；完整人眼视域和实体结果 TBD` |

## 5. 阶段 C：机构、动态间隙与安全接口

| ID | 复测问题 | 方法与最小证据 | 判定门槛 | 当前结果 |
|---|---|---|---|---|
| C-01 | A07 是否为同一套单移动脊柱机构并全行程无碰撞 | 四态 occurrence/实体一致性；同一固定套筒＋一件完整移动脊柱＋同一冠梁；Ride/Café 保持低态，Follow 与 A06 共铰折叠，Focus 仅移动脊柱、冠梁和其功能件执行受控 `+420 mm`；核对禁止 `stage_2/stage_3`、径向间隙、Focus 轴向捕获、隐藏榫槽、声学网避让、同轴性、公差极限、全行程扫掠和污染后循环 | 恰好一件移动脊柱；`stage_count=1` 且无 `stage_2/stage_3`；固定件零位移；Focus 捕获 `>=150 mm`；脊柱—冠梁实测公共体积为零、最短距离 `3 mm`，榫槽接合 `16 mm`、端余隙 `2 mm`、外观干缝 `4 mm`；声学网—结构榫公共体积为 0、干隙 `>=1.5 mm`；420 mm 位移满足冻结 gate；动态最小间隙与寿命：`TBD` | `静态 L1 以正式 pre/post-STEP 报告为准；动态 TBD` |
| C-02 | A09 桌机构是否被完整包覆且不晃动 | Café 右侧、Focus 双侧的三级直壁定向 squircle 桌腿、每叶一件连续收腰空心桌腹、base socket、Focus root crown、中央接缝、锁止、扫掠、侧向刚度和疲劳；清点并禁止 bridge/fairing/saddle/box-belly 残段回归 | 每个活动桌叶恰好一件桌腹单实体且 `service_sliver_count=0`；三级外截面 `72×70 / 60×58 / 48×46 mm`，级间干隙 `3.0 mm`、内通道 `40 mm`、socket 对一级 `>=2.4 mm`；Focus 对固定 A05 `>=1.5 mm`、中央膝部净通道 `250 mm`；静态不得裸露根部/级间机构；位移、刚度、循环数：`TBD` | `静态 L1 以正式 pre/post-STEP 报告为准；物理 TBD` |
| C-03 | A08 脚踏支持是否在两种姿态中完全包覆且可逆 | Ride 及 Café/Focus 可选展开态核对左右独立 `support_monocoque`、平台下托盘与连续根部壳；Follow/Café/Focus 收纳态核对同一 47 件机构进入 A01/A02/A08 遮蔽责任；四态核对固定导轨、端点锁、双通道脚区互锁和 A01 永久释放通道；执行 101 姿态、极限公差、底部和侧视检查 | 正常视角不得暴露危险运动件；同一 47 件 occurrence 不得在运动中增删或替换；固定根部和鼻壳通道不得随状态变形；人体脚区未清空时运动必须 fail-closed | `数字 B-Rep 通过不替代公差、负载、耐久、污染、夹伤与双通道电气样机验证` |
| C-04 | A08 排水是否真实有效 | 对 `STOWED` 与 `DEPLOYED_LOCKED` 的平台真实排水槽、展开态开底 root monocoque、排水/无电释放路径做数字核对；再做染色水流、污泥、毛发、坡度和冻融测试 | 两种姿态数字通道均满足正式 gate；残水量/排空时间：`TBD` | `静态 L1 以正式报告为准；实体 TBD` |
| C-05 | A10 无电释放和拉手是否可用 | 断电、戴手套、污损、低温、单手和应急操作 | 数字开口满足正式 gate；操作力、时间、可达性：`TBD` | `静态 L1 以正式报告为准；实体 TBD` |
| C-06 | A09 单侧桌展开是否避开人和物 | 杯具、设备、袖口、软包、儿童手模型的扫掠台架 | 清空检测与停止阈值：`TBD` | `TBD` |
| C-07 | 全产品夹剪点是否受控 | ISO/目标法规对应探棒、力/速度测量和风险分析 | 适用标准与阈值：`TBD` | `TBD` |
| C-08 | 线束与软管是否全行程受控 | 动态线束模型、实物透明台架、弯曲半径和磨耗循环 | 供应商限制与循环数：`TBD` | `TBD` |
| C-09 | 故障时是否能安全收回或救援 | 单点故障注入、失电、卡滞、传感失败、人工牵引 | 安全状态与时间：`TBD` | `TBD` |
| C-10 | 状态互锁是否阻止移动中展开 | HIL＋实车；移动、驻车、占用和身份组合矩阵 | 禁止组合 100% 被阻止 | `TBD` |

## 6. 阶段 D：结构、耐久与运输

| ID | 复测问题 | 方法与最小证据 | 判定门槛 | 当前结果 |
|---|---|---|---|---|
| D-01 | 主结构和外壳固定是否承载 | FEA＋应变计样机；额定载荷与误用载荷 | 载荷谱、安全系数：`TBD` | `TBD` |
| D-02 | 座椅、扶手、脚踏、桌面是否满足静强度 | 逐总成加载、偏载、冲击和保持试验 | 载荷与残余变形：`TBD` | `TBD` |
| D-03 | 机构寿命是否满足使用年限 | A05/A07/A08/A09 加速循环，含灰尘和温湿条件 | 循环数与失效率：`TBD` | `TBD` |
| D-04 | 产品是否抗倾覆 | 四态、不同载荷、坡道、门槛、桌面偏载 | 适用标准与角度：`TBD` | `TBD` |
| D-05 | 救援/搬运/系固点是否真实 | 拉力、误用和清晰度验证 | 载荷与标识要求：`TBD` | `TBD` |
| D-06 | 包装运输是否不伤 A 面和机构 | 振动、跌落、堆码、温湿和拆包复测 | 运输标准、等级：`TBD` | `TBD` |

## 7. 阶段 E：热、电池、RF 与 EMC

| ID | 复测问题 | 方法与最小证据 | 判定门槛 | 当前结果 |
|---|---|---|---|---|
| E-01 | 四态最坏工况温升是否受控 | 热仿真＋热电偶/红外；充电、爬坡、算力满载、日照、堵风 | 部件限值与触摸限值：`TBD` | `TBD` |
| E-02 | 外壳包覆是否破坏进排风 | 风量、压降、烟流、堵塞与风扇故障测试 | 风量/压差：`TBD` | `TBD` |
| E-03 | 热失控隔离与泄压路径是否成立 | 电池安全分析与法规试验方案 | 适用标准、传播门槛：`TBD` | `TBD` |
| E-04 | A04 侧 UWB 透波窗是否有效 | 暗室 S 参数、方向图、测距误差；含涂层和水膜 | 数字几何通道满足正式 gate；频段和 RF 阈值：`TBD` | `静态几何 L1 以正式报告为准；RF TBD` |
| E-05 | A01/A07/A10 感知窗是否满足性能 | 光学透过、雾化、污损、逆光、雨滴、刮擦后复测 | 各传感器阈值：`TBD` | `TBD` |
| E-06 | 整机 EMC 是否合格 | 辐射/传导发射、抗扰、ESD、瞬态和共存测试 | 目标市场标准：`TBD` | `TBD` |
| E-07 | 天线与金属装饰/线束公差是否鲁棒 | 公差极限样机和批次统计 | 去谐/吞吐/定位门槛：`TBD` | `TBD` |

## 8. 阶段 F：环境、材料与清洁

| ID | 复测问题 | 方法与最小证据 | 判定门槛 | 当前结果 |
|---|---|---|---|---|
| F-01 | 防水防尘等级是否成立 | 正式 IP 方案；四态、服务门和运动缝分别测试 | 目标等级：`TBD` | `TBD` |
| F-02 | 排水与冷凝是否不会进入关键区 | 雨淋、温湿循环、冷凝、不同坡度和堵塞组合 | 允许进水区与残水：`TBD` | `TBD` |
| F-03 | 材料是否耐 UV、皮脂、汗液和清洁剂 | 三套 CMF 试片加速老化；色差、光泽、裂纹、黏性 | 化学品清单与阈值：`TBD` | `TBD` |
| F-04 | 外壳是否耐刮擦和冲击 | 铅笔硬度、Taber、落球、边角冲击、轮椅/门框接触 | 等级：`TBD` | `TBD` |
| F-05 | 低温、高温和冻融后机构是否正常 | 环境箱＋全状态循环 | 温度范围与循环数：`TBD` | `TBD` |
| F-06 | 清洁人员是否不会误触机构 | 清洁任务分析、湿布/喷剂/手套测试 | 误触率与锁定策略：`TBD` | `TBD` |

## 9. 阶段 G：制造、公差、装配与维修

| ID | 复测问题 | 方法与最小证据 | 判定门槛 | 当前结果 |
|---|---|---|---|---|
| G-01 | 每个塑胶/金属件是否可制造 | DFM：壁厚、拔模、分型、滑块、筋柱、圆角、冲压/机加工路径 | 材料与工艺规则：`TBD` | `TBD` |
| G-02 | Class-A 面是否适合模具与涂装 | 模流、缩水、翘曲、浇口、顶出、喷涂遮蔽和返修 | 面差/色差/良率：`TBD` | `TBD` |
| G-03 | 公差栈是否保留功能间隙 | 极限法＋统计法；A05/A07/A08/A09/A10 重点分析 | 最小间隙、最大面差：`TBD` | `TBD` |
| G-04 | 装配是否有唯一基准和顺序 | 3D 装配仿真＋试装；紧固可达、扭矩、防错 | 工时、工具、返工门槛：`TBD` | `TBD` |
| G-05 | 服务件是否能无损拆装 | 授权维修演练；门、窗、密封、传感件、脊柱和桌机构 | 时间、重复次数、损伤门槛：`TBD` | `TBD` |
| G-06 | 密封与粘接是否受过程控制 | 表面处理、点胶、压缩量、固化和泄漏检验 | 过程窗口与量测：`TBD` | `TBD` |
| G-07 | 供应商能力是否满足外观与尺寸 | T0/T1/T2、FAI、MSA、SPC、Cpk、批次 CMF | Cpk/良率：`TBD` | `TBD` |
| G-08 | 量产测试是否覆盖关键失效 | EOL 功能、传感、互锁、释放、泄漏、身份清除 | 测试覆盖率与节拍：`TBD` | `TBD` |

## 10. 阶段 H：人因、状态语义与生态

| ID | 复测问题 | 方法与最小证据 | 判定门槛 | 当前结果 |
|---|---|---|---|---|
| H-01 | 未受训旁观者能否 5 秒判断状态 | 真实场景、无讲解、行为编码；含 2 m/5 m | 样本量与正确率：`TBD` | `TBD` |
| H-02 | 用户是否描述“任务与空间一起移动并恢复” | 90 秒旅程、开放访谈，不提供品类词 | 编码规则与门槛：`TBD` | `TBD` |
| H-03 | 急停/释放是否在四态可达可懂 | 不同身高、能力、手套、低照度和压力任务 | 时间、力、成功率：`TBD` | `TBD` |
| H-04 | Café 接近侧和禁止移动是否明确 | 对面人进入、杯具、交谈和中断场景 | 正确率与误入率：`TBD` | `TBD` |
| H-05 | Focus 隐私是否先于内容恢复 | 物理遮挡、相机指示、错误身份、离席、重新移动 | 禁止泄露 100%；时序：`TBD` | `TBD` |
| H-06 | 低电/断网/缺设备是否安全退化 | 故障注入；验证本地核心、解释和救援路径 | 场景覆盖率：`TBD` | `TBD` |
| H-07 | 任务恢复是否达到目标 | 正确用户、本地/联网、部分恢复和中断重试 | P95 10 秒目标；测量方案：`TBD` | `TBD` |
| H-08 | 儿童、宠物、软包、污渍是否被覆盖 | 形成性误用研究和风险回归 | 场景与样本量：`TBD` | `TBD` |
| H-09 | 转售/换用户是否无残留 | 身份、密钥、任务缩略图、路线和日志清除审计 | 0 可恢复前任数据 | `TBD` |

## 11. 阶段 I：法规、知识产权、试产与量产

| ID | 复测问题 | 方法与最小证据 | 判定门槛 | 当前结果 |
|---|---|---|---|---|
| I-01 | 产品分类和目标市场是否冻结 | 法规顾问书面意见、国家/地区清单 | 分类与市场：`TBD` | `TBD` |
| I-02 | 适用标准和认证计划是否完整 | 标准矩阵、差距分析、第三方实验室评审 | 标准号与版本：`TBD` | `TBD` |
| I-03 | 风险管理是否闭环 | 危害分析、FMEA/FTA、可追溯需求与验证 | 接受准则：`TBD` | `TBD` |
| I-04 | FTO 与专利策略是否完成 | 正式检索、权利要求分析和法律意见 | 法律签署：`TBD` | `TBD` |
| I-05 | 试产是否稳定 | EVT/DVT/PVT 分阶段审查、缺陷 Pareto、返工与良率 | 样本量、良率、停线门：`TBD` | `TBD` |
| I-06 | 量产变更是否受控 | ECN、偏差许可、追溯、软件/硬件配置和黄金样 | 流程签署：`TBD` | `TBD` |
| I-07 | 售后与召回路径是否就绪 | 维修网络、备件、诊断、事件上报和召回演练 | 服务指标：`TBD` | `TBD` |
| I-08 | 跨职能量产批准是否完成 | 工业设计、机械、电子、软件、质量、法规、供应链签署 | 所有必签项完成 | `TBD（BLOCKED）` |

## 12. 每轮复测的最低输出

每次复测必须保存以下内容；缺一项则结果为 `TBD`：

1. 测试对象的硬件、软件、CAD、材料和供应商版本；
2. 原始数据、照片/视频、环境条件、设备编号和校准状态；
3. 预先冻结的通过门槛，而不是测试后修改的解释；
4. 失败复现步骤、根因、纠正措施和回归范围；
5. 报告 SHA-256、责任人、复核人和日期；
6. 对四态和典型场景的影响判断；
7. 明确的 `PASS`、`FAIL` 或 `TBD`，不得使用模糊中间词；
8. 对数字 CAD 轮次，保存同次构建的正式 manifest、pre/post 报告、32 图 raster 报告、逐文件 SHA-256 和发布后只读制品闭包结果；
9. 对数字 CAD 轮次，明确记录 `BUILD_INCOMPLETE` 是否存在；标记存在时无条件判为未完成。

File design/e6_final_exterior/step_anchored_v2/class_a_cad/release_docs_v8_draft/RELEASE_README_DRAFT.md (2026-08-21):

# WorkCore E6 V8 最终外观候选发布说明（草案）

文档状态：`V8 数字 CAD 候选发布说明源；正式发布状态以 release_candidate_v8/class_a_skin_manifest.json 与 BUILD_INCOMPLETE 是否存在为准`

量产认证状态：`NOT CERTIFIED（当前禁止用于 Class-A、开模、法规或量产放行）`

数字几何门结论用语：仅当正式 manifest 引用的全部数字报告为 `PASS` 且 `BUILD_INCOMPLETE` 不存在时，方可使用 `GEOMETRY_GATE_PASS_NOT_PRODUCTION_CERTIFICATION`

## 1. 本草案的用途

本目录记录 WorkCore E6 V8 最终外观候选的设计边界、已有数字证据和进入工程样机前必须补齐的验证。它不是销售材料，也不是 Class-A 曲面放行、模具放行、安全认证或量产批准。

V8 是受控 `E6-DFR5-A07-SHARED-HINGE` 四主态 STEP 的独立外观层。DFR5 只把 Follow 的完整 A07 发生项修正到与 A06 共用的 `(160, 0, 515) mm` 铰链；Ride、Café、Focus 及两个可选脚踏子态与 DFR4 字节一致。受控 STEP 仅作为只读架构底图；V8 不以替换、缩放或移动受控架构来换取外观成立。E6-DFR3 与父版本 DFR4 保留为历史追溯输入，不得再作为当前发布基线。

## 2. 产品定义：一个物品的四种状态

Follow、Ride、Café、Focus 不是四个产品，也不是在同一底盘上临时堆出的四套附件。它们是同一件“个人场域载体”在不同物理前提下的状态转化：能力在闭合时被收住，在人进入、驻车、授权和隐私条件成立后按顺序显露。

| 状态 | 物理前提 | 当前外观表达 | 不得被误读为 | 正式用户验证 |
|---|---|---|---|---|
| Follow | 空载、允许伴随移动 | 同一梯形靠背折叠后形成唯一上表面；A08 为 `STOWED`；低位感知地平线；工作脊柱在其内部净空中被遮蔽；仅保留必要的机械急停与克制状态见证 | 行李箱、宠物机器人、裸露折叠车、额外箱盖 | `TBD` |
| Ride | 乘员进入并取得控制 | 同一 A08 为 `DEPLOYED_LOCKED`；脚踏、扶手、座背围绕人建立边界；桌面保持收纳；控制与急停可读 | 医疗椅、办公椅、外壳压过乘员主体 | `TBD` |
| Café | 已驻车、单侧桌面允许展开 | A08 主态为 `STOWED`、双脚可落地；当前 CAD 仅右侧桌面展开；另一侧保持开放；控制语义退居次位 | 坏掉的半张桌、仍可牵引移动的驾驶舱 | `TBD` |
| Focus | 已驻车、双桌与隐私前提成立 | A08 主态为 `STOWED`、双脚可落地；双桌形成工作边界；同一单一移动脊柱与冠梁从低态上移 420 mm，固定套筒不动；同一右侧 pod/摇杆/授权键保持扶手前端固定外露但牵引禁用；物理隐私件与光学窗分离 | “大桌版 Ride”、仍在等待驾驶的座椅、先亮屏后确认身份、静默开启相机 | `TBD` |

神秘感只来自“能力按条件出现”，不来自隐藏危险或制造意图不明。移动方向、驻车、故障、隐私关闭、接近侧和接管需求仍必须可读。该可读性的实体测试结果为 `TBD`。

Café/Focus 可在驻车、脚部路径和前方净空成立后显式进入 A08 `DEPLOYED_LOCKED` 可选子态；它们仍分别属于 Café/Focus，不新增主态，也不进入四主态 32 图。四主态及两个可选子态始终引用同一套 47 个 A08 生产意图 occurrence，只有受控刚体变换与端点锁销状态不同。旧六发生项和 `1.890987 kg` 分析质量已经失效，当前机构质量必须由 47 件 EBOM 与首件重新闭环。

## 3. V8 数字 CAD 证据边界

本节定义正式数字候选必须证明的内容，不在文档源中预先硬编码会随几何变化的零件数或检查数。正式数量、状态、时间戳和 SHA-256 只读取本次 `class_a_skin_manifest.json` 及其引用的 pre-export、post-export、post-STEP 与 QA 报告；旧轮次数字不得沿用。

只有下列责任全部由同一次正式构建报告证明为 `PASS`，且 `BUILD_INCOMPLETE` 不存在，V8 才能标记为数字 CAD 门通过：

- 四个状态均由相同基础外观链重建，并依次应用 V8 外观收敛、真实功能开口、A07 同一固定套筒＋单一移动脊柱＋同一冠梁和刚性件分区；
- A08 在 Follow/Café/Focus 主态为 `STOWED`、在 Ride 主态为 `DEPLOYED_LOCKED`；Café/Focus 的显式展开仅作为独立验证子态，不得混入四主态图像或用第二套脚踏几何替代；
- 受控四态 STEP 在构建前后字节数与 SHA-256 均匹配冻结基线；
- manifest 同时记录完整生成器、参数、设计简报、冻结约束与发布文档源的构建前后 SHA-256，构建期间任何源漂移均使发布失败；
- manifest 记录的全部最终 `SkinPart` 均为单一、有效、正体积 B-Rep 实体；
- pre-export、post-export 以及 post-STEP 检查均无硬失败，每个检查 ID 唯一并记录 `evidence_kind`；
- A01 前鼻壳在四态中均熔接同一永久 brow-and-crown 天气面：它从正常前视、站立俯视和斜上视角闭合脚舱内部，同时保持感知硬点、A04 干缝与乘员侧脚部通道；不得以状态盖板或相机规避替代；
- Follow 只有同一块 4 mm 空心梯形 A06 靠背折叠并直接形成唯一上表面，不叠加盖板；完整 A07 低态与 A06 共用同一铰链。Ride/Café 已能读到同一低位冠梁，Focus 只把单一移动脊柱、冠梁和功能嵌件上移 420 mm；
- 两件低矮空心 A04 靠背根肩固定在车身上并存在于全部四态，以至少 4 mm 全折叠行程间隙承接 A06 下方视觉体量；不得恢复仅在非 Follow 出现的 A06 根部 cheek 碎片；
- A03 以覆盖完整胎宽上冠的连续 C-wrap 轮罩、前后轴平面端回和内侧下翻吸收轮胎上部及传动区；轮端与 rocker 维修盖后的深色实体背衬阻止缝隙透出背景。外侧主皮只允许 `z=0–32 mm` 低位接地条外露并通过侧面 `z=20/55 mm` 开放/闭合探针；仅前后端回保留局部 `z=0–70 mm` 运动/排水让位并通过端部 `z=55/90 mm` 开放/闭合探针及跨轮胎宽度和上半部的 3×3 实体覆盖网格。四个端回还必须分别使用一件 `1.0 mm` 月岩体色可换冲击皮，与深色结构端回保持 `0.1 mm` 干隙并覆盖 `Y=88.6 mm、Z=71–314 mm`；深色结构端回自身通过 3×3 探针不构成视觉通过，正/后视不得读取为竖向半轮或整轮外露。四轮在 `-10/-5/0/+5/+10°` 的名义扫掠净距均不得低于 `15.5 mm`，轮罩名义外宽 `750.8 mm`；近齐平轮端盖使局部成品宽度为 `751.0 mm`，仍低于 `752 mm` 量产设计上限，随盖拆卸的 EPDM 背衬最小扫掠净距为 `15.6 mm`；
- 外包络同时执行逐面和总尺寸双锁：相对哈希绑定 DFR5 STEP 的纵向 `xmin/xmax` 各自最多增长 `25 mm`、横向 `ymin/ymax` 各自最多增长 `17 mm`，任何单面超限不得以另一侧余量抵消；Follow/Ride/Café/Focus 总长还分别受 `885/1111/906/1021 mm` 上限约束，成品总宽继续受 `752 mm` 上限约束；
- 左右 A05 扶手均为固定连续壳体，外观中不存在侧开铰链、连杆、释放拨片或相应运动分缝；A05 收纳面保持为低填充率精密周界揭缝，而非大面积假屏；
- A07 在四态中使用同一固定套筒、一件完成态移动脊柱与同一冠梁；`stage_2`、`stage_3` 属于被禁止的旧行李箱拉杆架构。正式报告记录固定/移动件径向间隙、Focus 末端至少 150 mm 轴向捕获、420 mm 单一位移、共铰链和跨态 B-Rep 一致性；脊柱以 16 mm 隐藏空心榫插入终端套口，保留 3 mm 径向装配间隙、2 mm 端余隙和 4 mm 外观干缝；下置声学网位于结构榫外侧且干隙不低于 1.5 mm，不得退回零距离面接触或嵌件穿模；
- Follow 折叠 A06 与 A04 座垫之间唯一允许的非零 common volume 是对明确非刚性泡棉的无乘员名义预压：深度不得超过 `22 mm`、公共体积不得超过 `70,000 mm³`，Ride/Café/Focus 必须为零；该例外必须同时通过专用几何门，且不替代占用互锁、供应商压缩永久变形曲线和实体循环试验；
- A08 的 47 个生产意图 occurrence 在四主态和 Café/Focus 可选展开子态中保持相同物理身份与刚性 B-Rep；平台、双固定导轨、双主卡匣、双捕获内轨、四连杆/轴承/护销、端点锁、同步轴、配重、手动释放和双通道脚区互锁均不得因收纳而删除。Ride 展开态与 Follow/Café/Focus 收纳态只改变受控变换和锁销啮合。旧六发生项与 `1.890987 kg` 已被替代，当前 EBOM、材料、紧固件、线束和首件质量仍为开放量产证据；
- Café 右侧及 Focus 两侧 A09 使用独立嵌套的直壁定向 squircle 桌腿，外截面 `72×70 / 60×58 / 48×46 mm`，相邻径向干隙 `3.0 mm`，最内机构通道 `40 mm`，且轴线与 Z 硬点不变；每个活动桌叶只保留一件连续收腰空心桌腹，旧 bridge、root fairing、saddle、方盒 belly 及其布尔残段全部退休。底部 base socket 对第一级实际干隙不少于 `2.4 mm`，Focus 顶部 root crown 收住上口，固定 A05 内缘以受控退让保持 `1.5 mm` 动静干隙，中央膝部净通道为 `250 mm`；Café 桌腹至固定 A05 保留 1.1 mm 干缝，中央接缝、锁止和维修边界仍有明确责任；
- 四态始终保留同一物理右侧 pod、joystick 与授权键，并以完全相同的 B-Rep 和世界坐标固定外露于右扶手前端；仅 Ride 允许牵引，Café/Focus 展开桌板及其真实手部操作包络都不得遮挡或迫使控制件移位；
- A10 后服务门的无电释放轴孔与拉手腔为真实减材开口；
- “最终 V8 外皮＋仅 `retain_exposed` 的受控保留件”满足正式生产边界锁；完整原型 STEP 仅作为哈希锁定的只读追溯底图，不冒充当前量产 BOM；
- 32 张正式图通过同一次 raster gate；该集合严格为 Follow、Ride、Café、Focus 四主态各 8 张，Café/Focus 可选脚踏展开子态不在其中；导出 STEP 回读、GLB 米制单位与节点清单、四主态以及两个可选脚踏展开子态的 pre/post-STEP 刚性碰撞矩阵、源 CAD 21 点运动扫掠及封闭制品集检查全部通过。

本轮数字摘要统一写作：`4 states / exact part and check counts recorded by the formal manifest / 0 hard failures required`。这只是数字 CAD 完整性结论，不构成动态安全、可制造性、Class-A、法规或量产认证。

### 3.1 受控 STEP 基线

| 状态 | 只读文件 | SHA-256 |
|---|---|---|
| Follow | `controlled_source_e6_dfr5/workcore_e6_dfr5_follow.step` | `f925527ce086f2b18b0c53312733aadd6fa69aebb541d158f260d9c33b1a88fc` |
| Ride | `controlled_source_e6_dfr5/workcore_e6_dfr5_ride.step` | `3bf21b0811845c0d0fc10fbd116c96fc2188cc6e7a54956cd5e383c6a48fbb89` |
| Café | `controlled_source_e6_dfr5/workcore_e6_dfr5_cafe.step` | `8118b34c83bde30f316717e028279de656db4640d1c1f74e2c7fb6c96ecddd88` |
| Focus | `controlled_source_e6_dfr5/workcore_e6_dfr5_focus.step` | `598ad5a8686989be548140c5629a1b996b85bc833f1672850c98da400626ed4c` |

任何一个哈希或字节数不一致，都必须把 V8 证据判为失效并重新审查；不得以更新基线值掩盖受控文件变化。

上述四态及两个可选脚踏子态共同受 `controlled_source_e6_dfr5/e6_dfr5_a07_hinge_manifest.json` 约束；该受控源 manifest 的冻结 SHA-256 为 `dc27774b66320f8580c7bcd7d23a5c0f97e8e2187a808809f8116e811bc601a4`。正式构建必须同时核对 manifest 与其列出的 STEP/GLB，不能只核对表中的四个 STEP。

## 4. 当前数字 CAD 没有证明什么

下列项目均未被静态几何门证明，结果统一为 `TBD`，并阻塞量产放行：

- Class-A 曲面：曲率连续性、斑马纹、反射线、面间高光流动、A 面公差和手工补面结果；
- 动态机构：全行程扫掠、变形件、线束/软管、密封压缩、轴承间隙、污染后运动、夹剪点与故障回收；
- 结构：乘员、桌面、脚踏、扶手、救援点、搬运点、跌落、冲击、疲劳、倾覆和寿命；
- 热：电池、驱动、充电、计算平台、日照、堵风道、热表面、低温启动与热失控隔离；
- RF/EMC：UWB、ToF、雷达/超声、Wi-Fi/蓝牙/蜂窝等天线的透过、去谐、互扰、线束辐射和法规测试；
- 防护与环境：IP 等级、雨淋、排水、冷凝、盐雾、灰尘、泥沙、清洁剂、消毒剂、UV、温湿循环；
- 材料与 CMF：真实色差、光泽、纹理、皮脂、刮擦、耐磨、阻燃、气味、老化和批次稳定性；
- 制造：材料牌号、壁厚、筋位、柱位、拔模、分型、滑块、缩水、翘曲、浇口、顶出、装配路径和模具寿命；
- 公差：GD&T、装配基准、间隙面差、密封压缩、机构累计误差、热胀冷缩、供应商工艺能力和量产 Cpk；
- 人因：5 秒无讲解识别、2 m/5 m 状态可读性、戴手套操作、色觉/听力差异、儿童/宠物/软包/污渍误用和应急救援；
- 软件与生态：身份、权限、隐私、部分恢复、离线、低电、错误设备、任务恢复 P95、数据清除和转售交接；
- 法规：产品分类、目标销售地区、适用标准、第三方实验室方案、认证样机和型式试验；
- 知识产权：正式先前技术检索、FTO、外观/发明专利范围与规避方案；
- 成本与供应链：目标 BOM、模具投资、工装、良率、维修件、备件年限、供应商能力和停产替代。

## 5. 当前发布状态

| 发布层级 | 证据 | 当前状态 |
|---|---|---|
| 受控输入未变 | `qa/input_pin_report.json`；manifest 中构建前后四态 STEP 哈希与字节数 | `以正式报告及 manifest 为准；必须 PASS` |
| 内存静态几何门 | `qa/v8_geometry_release_gate.json` 与 `validation_pre_export.json` | `以正式报告为准；必须 0 硬失败` |
| 导出 STEP 后静态几何门 | `qa/v8_geometry_release_post_step.json` 与 `class_a_validation.json` | `以正式报告为准；必须 0 硬失败` |
| Café/Focus 可选脚踏展开门 | `qa/rigid_pair_collision_cafe_footrest_open.json`、`qa/rigid_pair_collision_focus_footrest_open.json` 及对应 `post_step` 报告；源 manifest 同时给出各 21 点扫掠 | `以正式报告为准；四份 Class-A 静态报告及两份源扫掠均必须 PASS；不进入 32 图` |
| 完整刚性碰撞矩阵 | 四态 pre-export 与 post-STEP 报告；0.1 mm³ 硬门；无未解释白名单 | `以正式报告为准；四态均必须 PASS` |
| 导出后几何回读 | `qa/exported_part_step_reload_gate.json`；每件重新导入并比较拓扑、体积和边界签名 | `以正式报告为准；必须 PASS` |
| GLB 复核 | `qa/glb_units_inventory_gate.json`；米制单位、节点/几何清单及边界与 STEP 一致 | `以正式报告为准；必须 PASS` |
| 32 图交付门 | `qa/render_series_raster_gate.json`；四主态 4×8、1600×1200、唯一文件、构建后生成、hero 与 QA 不同；不含 Café/Focus 可选脚踏展开子态 | `以正式报告为准；必须 PASS` |
| 最终候选制品集完整性 | manifest 全部文件 SHA-256、0 缺失、0 额外、闭包 PASS 且 `BUILD_INCOMPLETE` 不存在 | `以正式 manifest 和只读复核为准；两者缺一不可` |
| 工业设计人工视觉评审 | 四态八视图、1:1 轮廓、实体 CMF、无讲解评审 | `TBD；raster PASS 不替代人工与实体评审` |
| Class-A 曲面放行 | A 面数据、曲率/高光、公差签署 | `TBD` |
| 工程样机 DVT | 结构、热、RF、环境、机构、人因 | `TBD` |
| 法规/认证 | 适用标准与第三方报告 | `TBD` |
| 模具与量产 | DFM、T0/T1、能力研究、试产审核 | `TBD` |
| 最终量产批准 | 跨职能签署 | `TBD（BLOCKED）` |

## 6. V8 候选交付物清单

正式候选使用下列固定结构；实际逐件数量、路径集合、字节数、SHA-256 和门状态以本次正式 manifest 为唯一索引：

- 四态逐件外皮 STEP：`<state>/parts/*.step`；
- 四态独立皮肤 STEP：`<state>/workcore_e6_class_a_skin_<state>.step`；
- 四态“只读受控架构＋最终皮肤”复合 STEP：`<state>/workcore_e6_class_a_<state>_with_read_only_underlay.step`；
- 四态 review GLB 与 QA overlay GLB：`<state>/workcore_e6_class_a_<state>.glb`、`<state>/workcore_e6_class_a_<state>_qa_overlay.glb`；
- 四主态 hero、QA overlay、front、rear、left、right、top、bottom 共 32 张 1600×1200 PNG；Café/Focus 可选脚踏展开子态仅属验证范围，不替换或扩充此正式图集；
- 根级导出前/导出后验证：`validation_pre_export.json`、`class_a_validation.json`；
- `qa/` 中的输入固定、pre/post-STEP 几何、pre/post-STEP 四态刚性碰撞、检查 ID、STEP 回读、GLB 清单、32 图 raster 与源处置报告；
- 源处置 JSON/Markdown、manifest 内零件/材料/metadata/路径清单与物理 occurrence 责任；
- `release_status.json`：只声明数字 CAD 状态，并保持 `production_certification_claimed=false`；
- `class_a_skin_manifest.json`：正式制品索引、逐文件 SHA-256 与 artifact closure 证据；
- `docs/`：本发布说明、工业化复测矩阵和视觉设计依据的同版副本。

存在 `BUILD_INCOMPLETE`、缺少 manifest、manifest 任一数字门非 `PASS`、制品闭包不一致或文档与 manifest 不是同版时，以上目录只能视为构建中间物，不得作为数字候选交付。

## 7. 发布纪律

1. 任一几何、材料、分件、状态姿态或受控输入变化，必须重跑全部数字门；不得只复测被修改的截图。
2. 静态 B-Rep 的 `PASS` 只能写成数字几何证据，不能扩写成动态安全、可制造或法规合格。
3. 所有豁免必须有物理界面类型、责任人、批准依据和过期条件；“视觉上看不到”不是碰撞豁免理由。
4. 未完成项目统一写 `TBD`；不得使用“基本完成”“预计无问题”“量产级”代替证据。
5. 当神秘感与安全意图冲突时，安全意图优先；当外观包覆与散热、感知、制动、维修冲突时，先解决工程路径，再冻结外观。

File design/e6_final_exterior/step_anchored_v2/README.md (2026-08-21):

# WorkCore E6 最终外观 — STEP Anchored V2

本目录是无几何锚定概念图的纠正版。当前外观构建的受控几何基线是版本化 `E6-DFR5-A07-SHARED-HINGE`；E6-DFR4 与 E6-DFR3 仅作为只读父版追溯：

| 产品状态 | 受控 STEP | 同源 GLB | 原始预览 |
|---|---|---|---|
| Follow | `class_a_cad/controlled_source_e6_dfr5/workcore_e6_dfr5_follow.step` | `class_a_cad/controlled_source_e6_dfr5/workcore_e6_dfr5_follow.glb` | 由同版 V8 渲染构建生成 |
| Ride | `class_a_cad/controlled_source_e6_dfr5/workcore_e6_dfr5_ride.step` | `class_a_cad/controlled_source_e6_dfr5/workcore_e6_dfr5_ride.glb` | 由同版 V8 渲染构建生成 |
| Café | `class_a_cad/controlled_source_e6_dfr5/workcore_e6_dfr5_cafe.step` | `class_a_cad/controlled_source_e6_dfr5/workcore_e6_dfr5_cafe.glb` | 由同版 V8 渲染构建生成 |
| Focus | `class_a_cad/controlled_source_e6_dfr5/workcore_e6_dfr5_focus.step` | `class_a_cad/controlled_source_e6_dfr5/workcore_e6_dfr5_focus.glb` | 由同版 V8 渲染构建生成 |

## 方法

1. 仅读取受控 GLB，生成与 STEP 拓扑同源的统一前右高位 3/4 参考图；
2. 把每张参考图作为工程内核/硬点/扫掠 underlay，而不是把样机外露零件当最终表面；
3. 生成时锁死轮心、总包络、机构拓扑、物理件 ID、相机和状态；
4. 在不侵入运动/视场/人体/服务边界的前提下，重新建立连续 Class-A cosmetic skin，包覆外露承力架、导轨、支撑、传动与零件森林；
5. 纠正图与原始几何参考并存，不能把概念图当尺寸证据；
6. 所有现有 STEP/STP 文件生成前后复算 SHA-256 树哈希。

## 目录

- `geometry_lock.md`：不得漂移的尺寸/拓扑与可重塑区域。
- `cladding_architecture.md`：Class-A 外覆分区、包覆对象与必须留下的功能开口。
- `source_refs/`：从同源受控 GLB 离屏渲染的几何参考及渲染脚本。
- `corrected_renders/`：早期图像纠正试验，已被 V7 CAD 全部取代，不得作为当前设计结果。
- `prompt_set.md`：每张纠正图使用的精确约束提示词。
- `qa/`：关联性检查、已知偏差与完整性证据。
- `class_a_cad/controlled_source_e6_dfr5/`：当前只读受控输入与 DFR5 manifest。
- `class_a_cad/release_candidate_v8/`：V8 正式输出目标；只有同轮全部门禁、32/32 raster 和 artifact closure 通过且不存在 `BUILD_INCOMPLETE` 时才成立。目录未生成或闭包未通过时不得引用为完成制品。
- `class_a_cad/`：V8 参数化源、验证器与发布脚本；`release_candidate_v3/v6/v7`、`visual_gate_v4/v5` 均为只读过程批次，不是当前设计结果。

## 解释边界

`corrected_renders/` 和 V7 及更早候选只保留为过程证据，不是当前尺寸、包覆或外观证据。V8 只有在 `release_candidate_v8/` 的 skin-only STEP、关联 STEP、GLB、32 张正式 PNG、manifest、QA 报告与只读制品闭包同时成立后才可引用；在此之前状态必须写作 `BUILD PENDING / NOT RELEASED`。即使数字门全部通过，它仍是 Class-A 方向/包络研究，不等同量产曲面、结构、安全或法规放行。

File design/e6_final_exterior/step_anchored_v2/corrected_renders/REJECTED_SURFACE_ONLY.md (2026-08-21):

# 已否决：仅换材质/圆角，不构成最终外观

`01_follow_final_surface.png` 与 `02_ride_final_surface.png` 虽然已与 STEP 同源几何建立关联，但把样机大部分外露结构直接保留为最终表面，只完成了 CMF、圆角和局部面差处理。

状态：**REJECTED / DO NOT USE**。

后续必须把受控 STEP 解释为工程内核/硬点/扫掠体，在其外建立独立 Class-A 外覆件，包覆不应外露的承力架、导轨、支撑、执行机构和零件森林；只在安全、感知、控制、散热、排水、接地和维修处有目的地开口。

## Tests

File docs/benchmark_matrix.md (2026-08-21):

# Mature-product benchmark matrix

This matrix records architectures worth borrowing.  A benchmark is not an automatic
selection: the exact part must pass load, life, environment, supply, cost and package
reviews before its vendor CAD becomes a controlled interface.

## Product-level adjacent systems for E6

The adjacent market is already dense: seated personal mobility, premium transformable
workstations, consumer following carriers and managed facility robots each prove part
of the WorkCore thesis.  They do **not** prove that WorkCore has equivalent performance,
regulatory status or field maturity, and their existence means that generic claims such
as "a chair with a desk" or "a cart that follows" cannot be treated as novelty.

| Adjacent product/system | Officially evidenced behavior | Pattern worth borrowing | What WorkCore must not infer or claim |
|---|---|---|---|
| [Honda UNI-ONE technology](https://global.honda/en/tech/Hands-free_seated_personal_mobility_device_UNI-ONE/?from=related) / [2025 corporate launch](https://global.honda/en/newsroom/news/2025/c250908aeng.html?from=latest_area) / [design interview](https://global.honda/en/design/interview/202509unione/) | Hands-free seated mobility steered by weight shift; a low position supports boarding/stability and a high position raises eye level. Honda moved from paid trials to corporate sales for use at destinations and designated facility areas, with service contracts. Its exterior deliberately hides wheels and uses a soft, publicly approachable form. | Launch a bounded destination service before promising universal public use; validate with paid design partners; make state height and boarding causal; hide complexity while keeping motion and personal-space intent legible. | WorkCore is not thereby hands-free, omnidirectional, type-certified, publicly deployable or equivalent in stability. Honda also occupies the broad "new seated mobility" territory, so that category alone is not novel. |
| [WHILL Model C2](https://whill.inc/us/whill-model-c2/) | A mature personal mobility product publishes a 51.9–52.8kg mass range, four-step disassembly, 760mm turning radius, 20km nominal range, 50mm obstacle capability and multiple seat/controller adjustments; US material also states FDA Class II status. | Publish configuration-specific mass and mobility limits; design transport as deliberate modules rather than a portability metaphor; provide fit adjustments, manuals, parts and support as part of the product. | WorkCore's stowed-model estimate is about 114.11kg and its pose-invariant base-SKU mass is not yet reconciled; it is not lighter, hand-portable or regulatory-equivalent. A component specification or ergonomic resemblance cannot inherit WHILL's tested range, obstacle, service or medical-device status. |
| [WHILL Autonomous Service](https://whill.inc/ca/mobility-service/how-it-works/autonomous-drive) | Deployment is an operational system: site assessment, mapping, system configuration, live hardware validation, staff training and passenger-flow simulation precede launch; monitoring, maintenance and later map/speed-zone updates continue afterward. | Treat ODD, route versioning, staff training, fleet visibility, rescue and post-launch change control as sellable service work, not installation footnotes. | Buying scanners or writing a route map does not make WorkCore autonomously safe. No public autonomy, staffing level or service readiness can be borrowed from WHILL evidence. |
| [Altwork Signature Station](https://altwork.com/products/altwork-signature-station) / [official FAQ](https://altwork.com/pages/faqs) | A premium workstation synchronizes body support, work surface and monitor through sit, stand and zero-gravity positions. Published information lists about 95kg product mass, pallet delivery, two-person assembly and dedicated service/support expectations. | Coordinate body, display and work-surface transitions; sell a high-value ergonomic experience; plan pallet delivery, installation, cable management, service access and owner education from day one. | A 95kg stationary workstation does not validate mobile stability, ride comfort, health outcomes or context continuity. It also demonstrates why high mass requires an explicit delivery story rather than "luggage" language. |
| [Piaggio Fast Forward gita](https://piaggiofastforward.com/) / [official FAQ](https://piaggiofastforward.com/faqs) | The consumer carrier uses computer vision and a tap to pair/follow rather than GPS; official communication emphasizes pedestrian etiquette and explicitly limits terrain such as sand, snow, mud and tall grass. | Use one-action owner pairing, clear follow/stop status, pedestrian courtesy and honest terrain boundaries; design cargo retention and everyday loading into the journey. | A successful consumer follow carrier does not establish WorkCore's owner recognition, braking, outdoor reliability, portability or safe operation around seated users. "It follows me" and hidden wheels are occupied adjacent ideas, not novelty claims. |
| [Piaggio Fast Forward kilo](https://piaggiofastforward.com/business/kilo) / [launch description](https://piaggiofastforward.com/blog/our-newest-product-launch-pff-kilo) | A facility-focused robot is specified at 66kg with 136kg payload, 8–10h operation, 360-degree 2D lidar plus eight ultrasonic sensors, push-button lead/follow behavior and mounting points for site-specific carts or shelving. It is positioned to join existing workflows with human oversight and without extensive new infrastructure. | Use a controlled B2B wedge; integrate with actual facility loads and routes; make lead/follow/stop behavior obvious; price and test the operator workflow, mounting interfaces and fleet/service layer. | Industrial human-following is not proof of safe personal mobility or public-space autonomy. WorkCore cannot claim equivalent payload, runtime, perception or deployment maturity, and a follow-cart concept by itself is not defensible novelty. |

### E6 cross-benchmark conclusions

- **Borrow the launch method:** Honda, WHILL and kilo all point toward bounded sites,
  operational assessment, staff readiness and continuing service.  This supports E6's
  controlled B2B2C design-partner/rental wedge, not an immediate unrestricted retail launch.
- **Borrow causal transformations:** UNI-ONE changes height for boarding/stability and
  eye-level interaction; Altwork coordinates posture, desk and display.  Every E6 motion
  likewise needs a user benefit, an interlock and a safe recovery path.
- **Tell the truth about mass:** WHILL designs explicit disassembly around roughly half
  E6's current stowed-model estimate; Altwork and kilo use delivery/industrial workflows. E6's pose-invariant base-SKU mass remains an open configuration-control gate. Its "luggage"
  metaphor may describe closed, quiet following behavior only.
- **Make autonomy an operation:** mapping, route change control, training, monitoring,
  maintenance and rescue are product scope.  A purchased perception component is not an
  autonomy or certification claim.
- **Place differentiation narrowly:** the potentially defensible territory is the exact
  four-state combination, fold-invariant low sensing, safe morphing causal chain and
  identity/physical-state/privacy-linked context restoration.  Formal prior-art search,
  claim charting and freedom-to-operate review are required before any novelty statement.

## Component-level mature-product references

| WorkCore function | Mature reference | What to borrow | What not to assume |
|---|---|---|---|
| Locking drawer travel | [Accuride 9300 series](https://www.accuride.com/en-us/products/drawer-slides/heavy-duty-slides/9300-drawer-slide-series) | Three-member full extension, lock-in/lock-out, accessible release lever, silencing bumper; published maximum rating up to 600 lb under specified conditions | Rating in the WorkCore orientation, shock load, pair spacing and mobile duty must be separately derated and tested |
| Lid/display positioning | [Southco E6/ST constant-torque hinge](https://southco.com/en_us_int/hinges/positioning-hinges/e6-st-constant-torque-position-control-hinges) | Factory-set torque, asymmetric lift/lower effort, zero-drift positioning, corrosion-resistant variants; family data states 20,000-cycle torque retention within ±20% | Do not use a friction hinge as the sole safety support for a load-bearing table or canopy |
| Powered lift architecture | [LINAK DL1A lifting column](https://www.linak.com/products/lifting-columns/dl1a) | Integrated guided column, published 1600 N maximum load per leg, controlled ergonomic motion and mature controller ecosystem | Current WorkCore mast package is custom and much narrower; vendor stroke, retracted length, bending moment and IP rating must fit before adoption |
| High-load two-stage lift | [LINAK DL2 lifting column](https://www.linak.com/products/lifting-columns/dl2) | Robust two-stage guide concept for technical workstations | Desk-column duty does not establish outdoor canopy wind resistance |
| Cassette awning drive | [Dometic 9500E 12 V cassette awning](https://media.dometic.com/externalassets/dometic-9500-manual-patio-case-awning-200-_64699.pdf) | Cassette packaging, 12 V tubular drive, limit management and protected stow state; reference manual lists 12 VDC, 3.7 A, 15 rpm, IP44 motor data | WorkCore's 800 x 620 mm canopy has different torque, wind, drainage and pinch risks; use architecture, not copied sizing |
| User posture and reach | [OSHA computer workstation eTool](https://www.osha.gov/etools/computer-workstations/checklists/evaluation) | Neutral shoulders/wrists, adjustable seat/work surface, thigh/leg clearance, waterfall seat edge | Compliance and comfort still require target-population trials |
| Accessible controls | [U.S. Access Board operable parts](https://www.access-board.gov/ada/guides/chapter-3-operable-parts/) | One-hand operation, low dexterity demand, <=5 lbf operating force where applicable, tolerance-aware reach placement | ADA building requirements do not by themselves certify a mobile product |

## Historical E2 adoption direction

These entries are retained for traceability.  E2 canopy and drawer decisions do not
override the E6 product definition, which removes the base canopy and changes storage.

- Use locking slides or an equivalent positive latch on every drawer because the product moves.
- Use constant-torque hinges only for lids/screens; use positive over-centre or pin locks
  for structural tables.
- Package a replaceable lift cartridge with controlled guide pads instead of machining
  the mast slide directly into cosmetic shells.
- Treat the cassette awning as a sealed service module with a drain path, replaceable
  fabric/roller assembly, torque-limited drive and independent stowed confirmation.
- Put frequently used controls inside the verified seated reach envelope and make all
  emergency/stow actions available without navigating the display.

## Historical E2 selected interface candidates

| Function | E2 candidate | Controlled facts used in CAD | Selection boundary |
|---|---|---|---|
| Drawer slide | [Accuride 3832-E10-DO](https://www.accuride.com/media/amasty/amfile/attach/5d3275f703c9dec3898e9331b075578e.pdf) | 250 mm closed length, about 254 mm travel, 12.7 mm nominal side space, 45.7 mm height, 45.5 kg pair rating | Detent open/closed is supplemented by a separate positive transport latch; mobile shock and life remain test gates |
| Drawer latch | [Southco R4-10-30-905-20](https://southco.com/en_us_int/r4-10-30-905-20) | Approximate 77 x 36 x 20 mm interface envelope and two-stage rotary-latch architecture | Final striker, release cable, corrosion and slam-load configuration must be selected with Southco |
| Mast actuator | [LINAK LA20](https://cdn.linak.com/-/media/files/data-sheet-source/en/linear-actuator-la20-data-sheet-eng.pdf) | Ø40 mm-class envelope, 240 mm candidate stroke, 2:1 motion multiplier, up to 2,500 N family rating | Exact built-in length, speed at load, IP option, brake/back-drive behavior and service life must be confirmed in a configured part number |
| Canopy cassette | [Dometic 9500E architecture](https://media.dometic.com/externalassets/dometic-9500-manual-patio-case-awning-200-_64699.pdf) | Cassette, tubular motor, limits, protected stow and replaceable fabric/roller principles | Its 15 rpm reference drive is too slow for E2's sub-8-second emergency target; E2 needs a separately qualified spring-assisted 60 rpm-class system |

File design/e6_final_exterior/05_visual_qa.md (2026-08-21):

# 05 — 视觉概念复核

复核依据为 `docs/e6_object_character_and_mystery_brief.md`、本目录 01–03 规范以及现有工程硬点。三张图锁定的是设计语言与状态关系，不是尺寸准确的 CAD 投影。

## 复核结果

| 项目 | 结果 | 说明 |
|---|---|---|
| 一件新物品，而非样机美化 | 通过 | 低位整体、嵌套上壳和统一曲率消除了方箱叠放与零件散落感 |
| 复古科幻 / 极简 / 平滑 / 高级 / 神秘 | 通过 | 气质主要由轨道仪器比例、暖矿物 CMF、烟熏功能材料和精确揭边形成，无道具化符号 |
| Follow 闭合完整性 | 通过 | 座、控制、桌和桅杆均被收纳；仍保留方向、感知与接地真相 |
| Ride 人为主体 | 通过 | 低靠背、开放座舱、脚踏与物理控制清楚；未形成高包围驾驶舱 |
| Café 社交非对称 | 通过 | 单侧桌叶显露、对侧开放；后续 CAD 必须用真实前移—旋转—回位轨迹实现 |
| Focus 工作场 | 条件通过 | 双桌和升起观测脊柱成立；后续需按 430 × 270 mm 双桌、705 mm 高度、10–20 mm 防夹缝与头部净空校正 |
| 感知不拟人 | 通过 | 低位连续语法中保留真实材料分段和短方向光标，不构成人脸 |
| 隐私 / 安全不神秘 | 通过 | 物理隐私片、机械急停和方向光标可见；最终灯语仍需冗余声/触觉验证 |
| 服务与清洁 | 条件通过 | 齐平服务门、可替换下裙和排水逻辑已表达，但实际拆装空间、紧固与液体路径需工程样机验证 |
| 工程几何一致性 | 未作为图像通过项 | 生成图不能证明轮心、间隙、人体、传感视场、扫掠体、散热或结构；必须在独立 Class-A CAD 中逐项回归 |

## 图像中不得直接抄入 CAD 的部分

- 任何由透视造成的轮距、轮心、壳体厚度和离地间隙；
- Follow 上盖分片、Café 桌支撑、Focus 桅杆截面和桌面悬挑的具体尺寸；
- 感知窗内部元件排布、急停底座、服务门锁和排水孔的生成式细节；
- 所有未被接口控制文件确认的曲面分件、紧固方式和材料边界。

## 下一阶段 Class-A 建模输入

1. 复制只读硬点到新的外观装配，先建立轮胎、人体、桌/脚踏/桅杆全行程、传感视场和服务工具禁止侵入体。
2. 以主视图的大体量、高光和三条主线建主表面，不以局部生成细节倒推结构。
3. 用四状态板校验同一壳体的闭合与显露逻辑；每个动作必须对应真实铰链、导轨、锁止、线束和无电释放。
4. 依据 CMF 板创建真实材料分区与可换件边界，再做 RF/IR/声学、阻燃、耐候、清洁和色差试片。
5. 每轮曲面冻结后，按 `03_cmf_and_release_gates.md` 回归相应 G0–G6 证据，不以“看起来可行”关闭问题。

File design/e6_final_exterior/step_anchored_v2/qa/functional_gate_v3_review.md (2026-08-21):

# WorkCore E6 最终外观功能门 V3 只读审查

Status: **FAIL — 当前 CAD 不能作为量产外观功能接口放行依据。**

本审查按 `e6_object_character_and_mystery_brief.md` 的原则执行：神秘感只能来自能力的克制收纳，不能来自隐藏运动意图、传感、故障、锁止、救援或服务路径。审查对象为四个受控状态 `Follow / Ride / Café / Focus`，以及当前 `skin_common.py`、`skin_lower.py`、`skin_upper.py`、`build_class_a_skin.py`、`validate_class_a.py`。未改动上述代码或任何受控 STEP。

本文件是功能接口/包覆责任审查，不是 Class-A、结构、功能安全、RF、声学、泄压或热管理试验放行。

## 1. 审查口径

状态缩写：`F=Follow`、`R=Ride`、`C=Café`、`X=Focus`、`ALL=F/R/C/X`。

外观中的功能对象必须属于以下四种之一，并在 manifest 中逐个绑定受控 occurrence：

1. `retain_exposed`：轮胎、座垫、天气密封等本身就是最终接触/运动/密封面，保留受控源件；
2. `replace_surface`：最终窗、膜、踏面、按钮或桌面皮替代样机外表面，但硬点和功能轴不变；
3. `conceal_behind_access`：充电、断电、制动释放等平时隐藏，但必须有明确的门、无电开启件和可达路径；
4. `internal_enclosed`：模块、线束、支架、导轨等完全退出正常视野，并由具体外壳承担包覆责任。

不能接受第五种状态：builder 仅从 final GLB 隐去源件，却没有与其硬点相连的最终代理或服务链。

受控功能件清单以四个实际状态 GLB/STEP 为准，而不是以 `build/parts` 目录中所有历史/备用零件为准。例如 `footrest_stowed.step`、下层抽屉和非 Focus 的 fill-light STEP 没有出现在四个受控状态 GLB 中，本轮不据此制造伪失败。

## 2. 立即阻断放行的 P0

| ID | 受控硬点/源件 | 当前最终代理 | 结论与建议几何修正 | 可直接实现的 hard check |
|---|---|---|---|---|
| P0-01 Focus 隐私片硬点漂移 | `mast_privacy_shutter_parked_focus`: X `[262.5,266.5]`, Y `[65,191]`, Z `[1443,1477]` | `A07_physical_privacy_shutter`: X `[262.5,266.5]`, Y `[32,158]`, Z `[1443,1477]` | 整件沿 Y 错移 `-33 mm`；这是为了把外观塞回 320 mm beam 而移动受控机构，不是包覆。恢复源中心 `Y=128`，为 Y=160..191 的 parked 部分增加真实端袋/外罩和装配隙。 | `function.focus.privacy_shutter.source_datum`: proxy/source 三轴中心和尺寸差均 `<=0.5 mm`；`function.focus.privacy_shutter.parked_pocket`: pocket 对源 shutter 全包络且最小隙 `>=2 mm`，不得移动源件来通过。 |
| P0-02 后 UWB 被金属门皮遮蔽 | `follow_uwb_rear_radome`: X `[327,330]`, Y `[-40,40]`, Z `[258,282]` | `A10_rear_uwb_radome`: X `[331,333]`, Y `[-40,40]`, Z `[258,282]`; 其后是镁门皮 `A10_rear_flush_service_door_skin`: X `[327.5,330.5]`, Y `[-153,153]`, Z `[246,414]` | 最终 radome 只是贴在实心导电门皮外；RF 路径仍被镁完全截断。门皮必须切贯穿孔，建议不小于源 80×24 mm 投影加每边 2 mm 密封/装配余量，再装独立非导电 radome。 | `function.all.rear_uwb.clear_rf_corridor`: 从源 radome +X 外表面到最终 radome 的 corridor 与任何 conductive/opaque part 交体积为 0；门孔 YZ 投影覆盖源件 `>=100%` 且每边余量 `>=2 mm`；材质必须声明 `rf_transparent=True`。 |
| P0-03 电池泄压喉口被缩小 | `battery_pressure_vent_duct`: X `[200,330]`, Y `[-21,21]`, Z `[157,199]`，+X 出口包络截面 42×42=`1764 mm²` | `A10_pressure_relief_vent_bezel` 最小开口 50×12=`600 mm²`；A10 tunnel 虽为 78×38，最终喉口仍控制流量 | 自由截面仅源出口包络的约 34%，缩小约 66%；`pressure_vent_unobstructed=True` 不能替代几何。扩大最终最小自由截面至经泄压工程签核的值，当前至少不得小于源出口有效面积，并保持朝后、远离乘员。 | `function.all.pressure_relief.minimum_free_area`: 沿 X 对完整通道分段求自由截面，`min_area >= signed_required_area`，在未签核前 `>= source_mouth_area`；`function.all.pressure_relief.no_skin_intrusion`: skin 与源 duct 交体积为 0。 |
| P0-04 后喇叭没有声学通路 | `service_rear_horn_behind_door`: X `[319,325]`, Y `[-30,30]`, Z `[386,414]` | 无 horn outlet；同一实心镁门皮覆盖整个 YZ 投影 | “门后可维修”不等于声音能到外界。门皮应有独立疏水声学膜/微孔格栅，或经验证的导声道；不能依赖普通门缝。 | `function.all.rear_horn.outlet_present`: 每态恰有一个 `rear_horn_acoustic_outlet`；`clear_acoustic_corridor` 不穿过实心镁/PC-ABS；必须有 `minimum_open_area_mm2`、膜材、IP 目标和声压证据引用。 |
| P0-05 四个下视 IR 最终面在错误一侧 | 四个 `follow_cliff_ir_window_*`: Z `[96,99]`，出射轴 `-Z` | 四个 `A02_cliff_ir_window_*`: Z `[99,102]`，X/Y 对齐但被放在源窗上方 | 代理位于内部一侧，无法成为最低外表面；builder 又把真实源窗从 final GLB 隐去。二选一：把源窗列入 `retain_exposed` 并加周边 bezel；或把最终窗置于源窗外侧/同一最终面并建立密封光筒。 | 每态按四角逐名检查；retain 路径要求源名出现在 `_source_keep`；replace 路径要求 `proxy.zmax <= source.zmin + 0.5`、XY 投影覆盖 `>=95%`、沿 -Z corridor 与不透明 skin 交体积为 0。 |
| P0-06 Ride/Focus 驾驶控件偏离 STEP | 受控 Ride/Focus pod X `[-305,-195]`, Y `[307,359]`, Z `[681,699]`; joystick Z `[699,727]`; authorisation Z `[699,707]` | `A05_right_removable_drive_pod` Z `[673,691]`，下降 8 mm；`A05_right_joystick` / `A05_right_authorisation_key` 均下降 11 mm | “下沉”是移动硬点，不是包覆，且会让最终图与 STEP 不对应。应围绕受控 pod 做 gasket landing，不改变按钮/摇杆的轴线和操作高度。 | `function.ride.drive_controls.source_datum` 与 `function.focus.drive_controls.source_datum`: pod/joystick/key 逐件 proxy/source 中心和功能轴差 `<=0.5 mm`；允许仅扩大外壳，不允许平移控制件。 |
| P0-07 右移乘扶手机构和正锁没有完整最终责任件 | `armrest_transfer_hinge_shroud_right`: X `[186,234]`, Y `[326,374]`, Z `[500,680]`; `link_shroud_right`: X `[124,226]`, Y `[326,368]`, Z `[477,503]`; `positive_lock_right`: X `[18,62]`, Y `[306,330]`, Z `[643,661]` | `A05_armrest_table_bay_shell_right` 只到 X=140、Y=367.5、Z=675；无 transfer-lock release/witness part | 源铰根/连杆有 X=140..234、Y=367.5..374、Z=675..680 超出 A05，且正锁被壳体语义吞没。增加独立 rear transfer-root fairing（围绕完整 sweep），并在源锁硬点提供机械释放/锁位 witness；不能显示裸 shroud。 | `function.all.right_transfer_mechanism.enclosed`: 源 hinge/link shroud 对应 `internal_enclosed` 且其 sweep 外包络由指定 proxy 全覆盖，运动隙 `>=3 mm`；`right_transfer_lock.interface`: 源 lock 必须绑定 release+witness，中心公差 `<=2 mm`，Ride 时锁止可读，Transfer 时无电可解。 |
| P0-08 Focus fill light 被无依据地删除 | 受控 Focus 左灯 X `[262,270]`, Y `[-151,-109]`, Z `[1449,1471]`; 右灯 Y `[109,151]` | 无 `A07_fill_light_*`；现有 smoked window 只到 Y `[-140,140]`，且 builder 隐去源灯 | 每侧有 11 mm 超出 smoked window，材料也没有可见光透过定义。增加两个与源光轴一致的最终灯窗/端袋，或把经过光学验证的组合窗口扩到完整源投影。 | `function.focus.fill_light.windows_bilateral`: 恰好左右两件或一个明确声明组合窗口；源投影覆盖 `>=100%`，光轴偏差 `<=0.5°`，opaque corridor 交体积 0，材质含可见光透过率证据。 |
| P0-09 后服务门缺少外部无电开启链 | `service_rear_flush_door` 后含 charge / disconnect / brake release；STRANDED_SAFE 要求无电制动释放 | `A10_rear_flush_service_door_skin` 只有 `quarter_turn_internal_release=True`，无外部 latch/handhold part | 内部 release 无法证明用户能从关门状态进入；充电和救援都依赖此门。增加防误触、可戴手套、无电的外部 quarter-turn/两动作释放和拉手凹区。 | `function.all.rear_service_door.access_chain`: `door -> external_release -> open_state -> charge/disconnect/brake` 链完整；release 必须 `manual_no_power=True`、bounds 位于门外表面、不得被门自身遮蔽；三个内部接口分别检查，不能由门的聚合 token 一次代替。 |
| P0-10 热排出接口没有受控外观边界 | 热架构仅声明 sealed cassette / underbody conduction / internal mixing，现有受控外观中无签核 heat-rejection surface、外部风道或不可涂覆区 | 当前 A01-A10 没有 `thermal_keepout` / `heat_rejection_surface` 责任件；validator 也不检查 | 泄压口不是日常散热口。没有热工程输入前不能声称外观未牺牲 thermal。必须由热团队冻结导热底板/换热器外表面、面积、涂层、周边间隙和清洁路径，再由皮肤让位。 | `function.all.thermal_interface.evidence`: 缺少受控 interface 或 signed evidence 即 hard fail；有接口后检查 skin 与 thermal keep-out 交体积=0、有效面积不减、无回流到乘员区、涂层/污染限制已绑定。 |
| P0-11 final GLB 的隐藏策略没有逐源件证明 | `_source_keep` 只保留 tyre/hub/seat cushion 和 Follow weather seals，其余源 geometry 一律从 final 隐去 | 只有部分新件（如 table top）声明 `final_presentation_proxy_for`；多数靠名称猜测 | 当前 final GLB 可以在没有真正包覆/通路时看起来“干净”。必须建立逐 state、逐 source occurrence 的 disposition ledger。 | `presentation.<state>.source_disposition_complete`: controlled GLB 中每个 geometry 恰有一种 disposition；`replace_surface` 必须绑定具体 proxy；`conceal_behind_access` 必须绑定 door+release；`retain_exposed` 必须进入 allowlist；未知/重复 disposition 直接 fail。 |

## 3. 必须保留或受控表达的完整接口清单

下表中的“当前状态”只说明 CAD 中是否有一个代理，不代表功能已验证。

### 3.1 低位感知、状态与 RF

| Gate ID | 状态 | 受控对象 | 当前最终 part | 当前风险/缺口 | Validator 谓词 |
|---|---|---|---|---|---|
| `FG3.sensor.front_tof.left/right` | ALL | `follow_front_tof_left/right_window` | `A01_front_left/right_tof_window` + `A01_perception_horizon_carrier` | 约 89 mm 前投影依赖三条光筒；现有 gate 只数窗口，不证明筒内无挡、无串扰、可排水 | Y/Z 中心差 `<=0.5 mm`；最终窗覆盖源投影 `>=100%`；沿 -X 光筒 corridor 与所有 opaque part 交体积=0；左右必须各一件 |
| `FG3.sensor.leg_scanner` | ALL | `follow_leg_scanner_window` | `A01_front_leg_scanner_window` + carrier | 与 ToF 同类；还需避免脚井/污水遮挡 | 中心/投影/corridor 同上；独立窗口恰好一件；最低排水口低于光筒最低点 |
| `FG3.sensor.tactile_bumper` | ALL | `follow_front_tactile_bumper_membrane` | `A01_front_tactile_bumper_skin` | 当前位置基本连续，但未验证源压力边覆盖、壳间缝和更换路径 | Y/Z 投影重叠 `>=95%`；最终膜位于最前外表面；源膜到代理间隙 `0..2 mm`；不得被 A01 nose 覆盖 |
| `FG3.sensor.side_ultrasonic.four_corners` | ALL | front/rear × left/right 四个 face | 四个 `A02_side_ultrasonic_face_*` | 当前 geometry 有四个，但现有 coverage 只要求 `minimum_count=2 + bilateral`，可少掉前/后各一件仍通过 | 按 `{front_left,front_right,rear_left,rear_right}` 精确集合检查；中心差 `<=1 mm`；外法线一致；每件 corridor 无不透明 skin |
| `FG3.sensor.cliff_ir.four_corners` | ALL | 四个下视窗 | 四个 `A02_cliff_ir_window_*` | **P0-05**，最终面在源窗上方 | 采用 P0-05 的 egress-axis/retain-or-replace 检查 |
| `FG3.rf.side_uwb.left/right` | ALL | `follow_uwb_side_radome_left/right` | `A04_side_uwb_radome_left/right` | 位置有代理，但未检查 paint/镁门/紧固件造成的 RF shadow | 左右各一；中心差 `<=8 mm` 仅在有明确 RF corridor 时允许；corridor 内不得有 conductive part；材质/涂层介电证据必填 |
| `FG3.rf.rear_uwb` | ALL | `follow_uwb_rear_radome` | `A10_rear_uwb_radome` | **P0-02**，镁门皮阻断 | 采用 P0-02 |
| `FG3.sensor.rear_tof` | ALL | `follow_rear_tof_window` | `A10_rear_tof_window` + A10 through-tunnel | 当前 A10 已切 tunnel，但未把源窗、tunnel、最终窗作为同一光路验证 | Y/Z 中心差 `<=0.5 mm`；+X corridor 无挡；tunnel 最小截面覆盖源窗 `>=100%`；最终窗可从外部清洁/更换 |
| `FG3.status.rear` | ALL | `hmi_rear_status_light` | `A10_rear_status_lens` | 存在，但“2 m 可读、非颜色冗余”只能由体验样机证明 | CAD 检查位置/外露/不被门遮；evidence 检查 2 m、5 秒、色觉/听力差异和移动/停稳/故障语义不复用 |
| `FG3.rf.hidden_antennas` | ALL | `follow_hidden_backrest_antenna_left/right` | 无独立 radome；依赖 A04/A06 非导电皮肤 | 隐藏天线可以不显露，但必须有 RF keep-out；当前没有 proxy binding/涂层/金属禁区 | 左右 antenna occurrence 均绑定 `internal_enclosed` 和 `rf_keepout`; keep-out 与 conductive skin/fastener 交体积=0；皮厚、涂层、介电与 OTA evidence 必填 |

### 3.2 HMI、控制权与安全状态

| Gate ID | 状态 | 受控对象 | 当前最终 part | 当前风险/缺口 | Validator 谓词 |
|---|---|---|---|---|---|
| `FG3.hmi.left_display` | ALL | `hmi_status_display_left` | `A05_left_status_display_window` + bezel | 代理存在；缺少 source/proxy datum binding 和可视角/眩光证据 | 中心、倾角、有效显示开口与 source 差 `<=0.5 mm/0.5°`；无壳遮挡；材料/evidence 绑定 |
| `FG3.hmi.qi_target` | ALL | Qi coil / presence-temperature sensor | `A05_left_qi_target_ring` | 目标环存在；未检查线圈轴、金属 keep-out、FOD/热传感区域是否被最终材料改变 | 目标环/coil 同轴 `<=1 mm`；规定半径内无导电 skin；最终堆叠厚度与 Qi/FOD/温升 evidence 必填 |
| `FG3.safety.mechanical_estop` | ALL | `hmi_mechanical_emergency_stop` | `A05_left_mechanical_emergency_stop` + guard | 按钮 proxy 与源位置一致；现有 validator 主要靠名称/大范围位置 | 按钮轴/中心/直径逐件绑定；外部可达 corridor；guard 不侵入操作圆柱；按钮必须 source-linked 而非仅有红色圆柱 |
| `FG3.hmi.drive_pod` | R/X；F/C 收纳 | pod / joystick / authorisation key | 三个 A05 right parts | **P0-06**；此外状态逻辑必须明确 Focus 是停驶但 pod 是否保留 | R/X 逐件 datum check；F/C final 不得出现外部 drive pod；X 若保留需 `drive_disabled=True` 的状态证据，不能把存在等同于授权 |
| `FG3.safety.right_transfer_lock` | ALL，Transfer 时解锁 | right transfer hinge/link/positive lock | 无专门最终 release/witness | **P0-07** | 采用 P0-07，并加 Ride/Follow/Café/Focus 的 locked witness 与 Transfer 的无电 release 状态矩阵 |

### 3.3 声学、环境、泄压与热

| Gate ID | 状态 | 受控对象 | 当前最终 part | 当前风险/缺口 | Validator 谓词 |
|---|---|---|---|---|---|
| `FG3.acoustic.lower_voice.four_slots` | ALL | 左右各两个 voice acoustic slots | 四个 `A02_acoustic_mesh_*` | 当前有四个；现有 coverage 只要求两件且 bilateral | 精确要求 `left_1,left_2,right_1,right_2`；中心差 `<=1 mm`；开孔面积、膜材、IP、声衰减 evidence 必填 |
| `FG3.acoustic.mast_microphone` | ALL，隐私状态仍需语义明确 | mast microphone array | `A07_microphone_acoustic_mesh` | 有 underside mesh，但没有 array-to-mesh corridor/遮挡检查 | corridor 无挡；mesh 投影覆盖 array；水膜/风噪/声衰减 evidence；错误身份/旧会话不得自动沿用的系统证据另行检查 |
| `FG3.environment.mast_air_exchange` | ALL | mast environment sensor | `A07_environment_sensor_grille` | 有 grille；未验证空气交换路径、冷凝和 Follow 折叠态朝向 | source-to-grille corridor 无挡；最小自由面积；所有姿态不形成积水杯；疏水膜和响应时间 evidence |
| `FG3.acoustic.rear_horn` | ALL | service rear horn | 无 | **P0-04** | 采用 P0-04 |
| `FG3.pressure_relief` | ALL | battery pressure vent duct | `A10_pressure_relief_vent_bezel` | **P0-03** | 采用 P0-03 |
| `FG3.thermal.heat_rejection` | ALL | 日常热排出/导热面 | 无冻结接口 | **P0-10** | 采用 P0-10；泄压口不能代替散热证据 |

### 3.4 排水、密封与可清洁路径

| Gate ID | 状态 | 当前表达 | 当前风险/缺口 | Validator 谓词 |
|---|---|---|---|---|
| `FG3.drain.follow_weather` | F | builder 保留 `travel_front_tpe_water_lip`、`travel_hinge_local_weather_bridge`、左右 `travel_side_tpe_seal_drain_*` | 这是正确的 `retain_exposed` 思路，但 validator 不验证 final GLB 确实保留四件、A06/A07 没堵住它们 | 精确 source-name allowlist；四件均存在；skin 与排水 outlet 交体积=0；左右出口低于轨道最低点 |
| `FG3.drain.A01_optical_tunnels` | ALL | 无明确 drain part/metadata | 三条长光筒可能积水、泥浆或清洁液；“窗口存在”不足 | 每条 tunnel 有独立低点 drain/clean path；outlet bounds 低于 cavity zmin；截面和堵塞检查 evidence |
| `FG3.drain.A02_side_shells` | ALL | 每侧三个几何 drain notch，但没有独立语义记录 | 注释/boolean cutter 不会被 manifest/validator稳定识别 | 左右各三个 outlet，按位置 X≈`-300,-20,235` 检查；开口穿到最低边；不得与 cliff window corridor 相交 |
| `FG3.drain.A04_seat_ring` | ALL | `A04_open_u_seat_pan_ring` 有两条 liquid path | 仅 metadata count；未验证路径连通/不流入 caddy | 左右各一，出口低于 ring cavity；与 caddy/harness keep-out 不相交 |
| `FG3.drain.A05_table_cassettes` | ALL；展开态更关键 | cassette door/exit throat 有 seal，无 drain | 灰尘、杯液或雨水可进入 430 mm 侧舱，当前没有最低点出口 | 每个物理 cassette 在 door/exit 两种状态都有 drain；不向 HMI/Qi/乘员排液；state-conserved physical ID |
| `FG3.drain.A08_footrest` | R/C/X | tread 3 slots、两 boot drain、两 collar drain | 部件存在；现有 validator 不证明贯通且不朝轮胎/电气喷液 | 三个 tread 槽 + 左右 boot/collar 出口精确计数；所有开口贯通；排液落点避开轮胎接触和电气接口 |
| `FG3.drain.A09_focus_seam` | X | 左右 `A09_focus_centre_seam_seal`，保持 12 mm seam | 表达合理；只检查 AABB gap，不证明排水/逃生/夹指路径贯通 | gap `10..14 mm`；两 seal 不相交；沿 -Z 有连续逃生/排水 corridor；锁件不得桥接 gap |
| `FG3.drain.A10_rear_apron` | ALL | A10 三个 bottom drain breaks | 存在；generic `all.drainage` 可能被任一别处 token 误满足 | rear apron 必须恰有三处、贯通到 zmin，且避开 rear ToF/pressure vent corridor |

### 3.5 门、人工释放、锁止和救援

| Gate ID | 状态 | 受控对象 | 当前最终 part | 当前风险/缺口 | Validator 谓词 |
|---|---|---|---|---|---|
| `FG3.service.upper_equipment_doors` | ALL | 左右 upper drawer/cots latch | `A04_upper_equipment_door_left/right` + release | 门已包住实际四态 GLB 中的上层 drawer fronts；release 与源 latch 不同硬点，需要证明机械 linkage、开门扫掠和锁位 | 左右各一门/一 release；door 对源 drawer 投影覆盖；闭态间隙、开态扫掠；release 绑定 source latch，不能只靠聚合 token |
| `FG3.service.daily_caddy` | ALL | unpowered access lid | `A04_daily_caddy_flush_hatch` | 外盖位于源 lid 上方，允许二级访问，但未证明从外盖到源 lid 的连续取出路径和无电手指入口 | `outer_hatch -> source_lid -> bin` access chain；所有中间壳不堵；`manual_no_power=True`；需要 handhold/release part 或可证明的 lift edge |
| `FG3.safety.footrest_lock_release` | R/C/X | deployed footrest / manual latch / two supports | A08 top/tread/perimeter、两 boot、两 body collar、manual release shell | 包覆方向正确；缺少锁止 mechanical witness、手套/无电操作包络和完整运动 sweep | proxy/source latch 中心差 `<=2 mm`；release corridor；`manual_no_power=True`；左右支持全 sweep clearance；锁止 witness 在 Ride 可读 |
| `FG3.rescue.recovery_handle` | ALL | stowed crossbar + left/right positive latches | `A04_recovery_handle_grip_shell` + `grip_inlay` | 新增 grip inlay 合理；但一个聚合 `positive_latches` token 不能证明左右两锁可触/已锁，也未检查拉出 sweep | source crossbar 全包覆但 grasp corridor 保留；左/右 latch 分别绑定 release/witness；开底手包络；stowed/deployed sweep 和 113 kg 级单人救援 evidence |
| `FG3.service.rear_door` | ALL | door / charge / disconnect / brake release | A10 door skin | **P0-09**；现有 `_extract_openings` 会把一个门的聚合 metadata拆成四个“已满足” opening，属于假证据 | 三个内部接口分别绑定 occurrence、位置和 door-open access；外部 release 单独 part；服务门闭态不等于内部接口可访问 |
| `FG3.service.charge_port` | ALL；Travel/charging | guarded charge port | 门后，无独立 final proxy | 平时隐藏正确，但必须能无电开门并插接，线缆不得跨救援/排水路径 | door-open state 中 connector envelope 无挡，插拔 corridor/弯曲半径/应力释放；闭态有密封和状态联锁 |
| `FG3.service.battery_disconnect` | ALL；Service | guarded disconnect | 门后 | 需要防误触、锁定/挂牌和无电进入 | access chain + two-action guard + lockout evidence；不得被 charge cable 或门铰遮蔽 |
| `FG3.service.brake_release` | ALL；STRANDED_SAFE | guarded brake release | 门后 | 必须在整机无主电时可达，且松手/复位逻辑明确 | `manual_no_power=True`；门和 release 均可无电；操作包络；释放状态必须有机械 witness，不能只靠屏幕 |

### 3.6 桅杆与工作感知

| Gate ID | 状态 | 受控对象 | 当前最终 part | 当前风险/缺口 | Validator 谓词 |
|---|---|---|---|---|---|
| `FG3.mast.shrouds` | ALL | outer/inner mast、guides、reeving、harness | `A07_mast_fixed_outer_sleeve`、`moving_inner_sleeve`、`root_transition_fairing`，F 另有 cassette cover | 当前有最终套件；仍需证明完整 source mechanism containment、wiper/pinch/污染界面，而不是只检查存在和 3 mm clearance | source mechanism 各 occurrence 绑定 `internal_enclosed`；外包络全覆盖；移动成员 sweep clearance；上下端 wiper/排水/pinch gap；Follow cassette 对完整折叠 sweep 检查 |
| `FG3.mast.lock_pins.bilateral` | ALL | 左右 mast lock pin | fixed sleeve 上两个 slots（同一 part metadata） | 现有 coverage 只要求一个匹配 part，无法证明两个真实孔和左右硬点 | 精确要求 source `-1/+1` 两个 station；slot 中心/尺寸与源 pin 公差；每侧独立 inspection/release corridor；一侧缺失即 fail |
| `FG3.mast.camera_depth_window` | ALL | 4K + depth/IR camera | `A07_sensor_beam_smoked_window` | 一个组合窗口可接受，但必须明确两光轴和涂层区域；不能仅凭 280×40 黑条 | 两 source camera 投影均在可透区域；各 optical corridor 无挡；可见/IR 透过、畸变、加热/结露和清洁 evidence |
| `FG3.mast.privacy_shutter` | F/R/C closed，X parked | physical shutter | `A07_physical_privacy_shutter` | **P0-01** | 采用 P0-01；另要求闭态遮住 camera active apertures，parked 态不遮 camera/fill-light，状态可在 2 m 读出 |
| `FG3.mast.fill_light` | X | left/right fill light | 无 | **P0-08** | 采用 P0-08 |
| `FG3.mast.microphone_environment` | ALL | mic array / environment sensor | acoustic mesh / grille | 代理存在；需 corridor、姿态排水和隐私状态证据 | 采用 3.3 对应检查 |

### 3.7 桌板、升降和正锁

| Gate ID | 状态 | 受控对象 | 当前最终 part | 当前风险/缺口 | Validator 谓词 |
|---|---|---|---|---|---|
| `FG3.table.cassette_state` | F/R 两门闭；C 左门闭/右 exit；X 双 exit | 同一物理左右 table cassette | `A05_table_cassette_door_*` 或 `exit_bezel/throat_seal_*` | 当前状态矩阵已表达；仍需同一 physical ID、排水、夹指和门锁证据 | 每 state/side 恰有 door XOR exit；同一 occurrence ID 守恒；deployed leaf 对应 side 必须 exit；stowed leaf 必须 door；不得生成第二套桌件 |
| `FG3.table.final_leaf_surface` | C 右；X 左右 | `desk_panel_left/right` | `A09_table_top_skin_*`、edge band、underbelly | 表面代理已新增，但 top/edge 与只读源 panel 占据同体积；必须明确是 `replace_surface` 而非另加碰撞实体 | 每叶恰有一 `final_presentation_proxy_for=desk_panel_*`; disposition=`replace_surface`；若 additive 则与 source 交体积=0；若 replacement 则需被替换层厚度/体积/装配定义 |
| `FG3.table.lift_boots` | C 右；X 左右 | lift tube/column boot | 三段 `A09_table_lift_boot_*` + root fairing/bridge | 三段视觉表达已加入；需证明全 stroke、顶部 11 mm、wiper 和夹指界面完全受控 | source tube/boot 全 sweep 包络在 final boot/root 内；最小径向隙；三段重叠不拉脱；顶部/底部 wiper 和 drain；不得只检查 bbox 高度 |
| `FG3.table.cafe_locks` | C | translation lock + rotation lock pin | root fairing openings、release paddle、positive-lock witness | part 已有；release paddle 与源 lock 之间是未定义 linkage，锁止状态不能只由装饰环暗示 | 两个 source lock 分别绑定 station；release linkage ID；source/proxy 中心容差；90°/80 mm 两终点 mechanical witness；左开放侧不得出现控制件 |
| `FG3.table.focus_two_lock_stations` | X | source lock pins/latches at X=-555/-255 | 左右各两个 `A09_focus_lock_release_paddle_*`，edge/top/underbelly openings | 源架构是两个 station，当前生成四个 leaf-local paddle；可以是双侧联动，但现有 CAD/validator直接假定“四个独立”而没有 linkage 证明 | 精确要求 station ID 集合 `{-555,-255}`；每 station 恰有一个 source lock；若双侧各一 paddle，二者必须共享同一 mechanical linkage ID、单侧释放故障策略和状态一致性，不能用 part 数量代替架构 |
| `FG3.table.focus_centre_gap` | X | 12 mm seam / two centre latches | edge/top/underbelly cutouts + two seam seals | AABB gap 当前可检查；还需保证锁/释放不桥接逃生和排水 corridor | 最终 gap `10..14 mm`；任一非允许 lock pin 对 seam corridor 的占用受控；无锋利边；无电 release 后可在 10 s 逃生的实物 evidence |
| `FG3.table.manual_no_power_release` | C/X | table locks | Café/Focus paddles | 材质和命名暗示机械件，但 metadata 没有统一 `manual_no_power=True`、操作力和手套包络 | 每个物理 lock station 有无电 release；reach cylinder 无壳/杯/桌边干涉；操作力、戴手套、5F～95M 和 10 s 逃生 evidence |

## 4. 当前 validator 的假通过路径

1. `_proxy_parts` 只按 part 名或 `functional_opening` token 匹配，没有要求绑定具体 source occurrence；一个外形相似的假窗口也可通过。
2. `_add_proxy_gate` 多数只数件数和左右侧，不检查功能轴、外露方向、光/RF/声/气 corridor 或源硬点。
3. `coverage.*.A02.ultrasonic_faces` 最少只要两件且左右都有，四角系统可缺一半。
4. `coverage.*.A04.equipment_release` 最少只要一件，不能证明左右门各自可开。
5. `coverage.*.A07.lock_pin_access` 一个 sleeve 的 token 就能通过，不能证明左右两个 slot 与两个源 pin 对齐。
6. A09 的 lock/release token 同时写在 edge、top、underbelly、root fairing 和 paddle 上，聚合 shell 能冒充真实锁件；应按 station/source occurrence 去重。
7. `_extract_openings` 会把 `service_aperture_mm` 或一个 door 的聚合 metadata 复制成 rear door、charge、disconnect、brake 四个 opening；没有 door-open access chain。
8. `all.drainage` 只需任何一个 metadata key 含 `drain`，不能证明每个液体低点都有出口。
9. clearance validator 只检查 tyre/rocker/mast，不检查 source-proxy hardpoint 对齐、source 被皮肤遮挡或 conductive/opaque material 插入功能路径。
10. `_source_keep` 是 presentation allowlist，不是功能覆盖证明；当前 builder 在校验前就会隐藏所有未 allow 的源件，造成后 UWB、horn、fill light 等“图上干净、物理失效”。

## 5. 建议新增的 validator 数据契约

每个最终功能 proxy 至少增加以下 metadata；缺失时不得进入量产外观 PASS：

```text
source_occurrence_ids: [controlled GLB/STEP occurrence names]
disposition: retain_exposed | replace_surface | conceal_behind_access | internal_enclosed
functional_axis: +X | -X | +Y | -Y | +Z | -Z | radial
exposure_states: [follow, ride, cafe, focus]
access_via: optional final door occurrence
release_via: optional final release occurrence
manual_no_power: true|false
minimum_open_area_mm2: optional signed requirement
material_function: optical_ir | optical_visible | rf_transparent | acoustic_transparent | pressure_vent | drain | touch | structural_cover
lock_station_id / linkage_id: required for every positive lock and release
evidence_refs: RF / optical / acoustic / IP / thermal / usability / safety test identifiers
```

建议在 `validate_class_a.py` 增加以下通用 helper，而不是继续堆名称关键词：

```text
require_source_disposition_complete(state)
require_proxy_datum(source, proxy, center_tol, angle_tol)
require_projected_coverage(source, proxy_or_aperture, axis, ratio, margin)
require_clear_functional_corridor(source, exterior, axis, forbidden_materials)
require_minimum_free_area(corridor, signed_area)
require_access_chain(exterior_door, release, internal_interface, no_power)
require_lock_station(source_lock, witness, release, linkage_id, states)
require_drain_path(cavity_low_point, outlet, minimum_area)
require_source_sweep_enclosed(source_occurrences, proxy_parts, clearance)
```

## 6. 建议实现顺序

1. 先冻结 source-disposition ledger，并让 final GLB 对任何未绑定源件直接构建失败；
2. 修复 P0-01～P0-09 的几何关系，P0-10 等待热工程冻结接口；
3. 把四类 corridor（光学、RF、声学、泄压）和三类 access chain（服务门、无电释放、正锁 station）写成 B-Rep hard checks；
4. 再补逐区域排水、密封、清洁和手套可达 checks；
5. 最后运行四态 STEP 复导、source hash、运动 sweep、正投影/QA overlay 和 1:1 实物功能验证。

只有上述 hard checks 全部通过，才能说“外露部件已被真正包覆，同时功能接口没有被外观牺牲”。当前结果仍是方向 CAD，不能称为量产最终外观放行。

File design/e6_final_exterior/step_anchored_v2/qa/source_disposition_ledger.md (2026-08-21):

# WorkCore E6 controlled-source disposition ledger

Status: **PASS**

This ledger is generated from the actual geometry keys in the four controlled GLBs. It is a presentation/cladding-responsibility contract, not a substitute for optical, RF, acoustic, pressure, thermal, motion or production validation.

A07 state truth is geometry-gated elsewhere: Ride/Cafe are the same readable low pose on X=310; Focus keeps the fixed outer transform and moves only the inner/terminal +420 mm; Follow shares the A06 hinge and is covered by that same trapezoidal backrest. Proxy names in this ledger cannot prove those B-Rep facts.

No unmatched occurrence is defaulted to `internal_enclosed`; a new source name makes generation fail until explicitly reviewed.

A01--A10 proxy-name verification: **not_performed**.

## Completeness

| State | GLB occurrences | Ledger entries | retain_exposed | replace_surface | conceal_behind_access | internal_enclosed | trace_only_retired | Unknown | Duplicate |
|---|---:|---:|---:|---:|---:|---:|---:|---:|---:|
| follow | 180 | 180 | 8 | 52 | 22 | 95 | 3 | 0 | 0 |
| ride | 176 | 176 | 4 | 57 | 19 | 93 | 3 | 0 | 0 |
| cafe | 189 | 189 | 4 | 56 | 21 | 105 | 3 | 0 | 0 |
| focus | 196 | 196 | 4 | 62 | 20 | 107 | 3 | 0 | 0 |

Total: **741 / 741** occurrences; unknown **0**; duplicate **0**.

## Controlled GLB fingerprints

- `follow` — `design/e6_final_exterior/step_anchored_v2/class_a_cad/controlled_source_e6_dfr5/workcore_e6_dfr5_follow.glb` — SHA256 `337e21e6335966bc0695e2f18af9e3a671db24072dfaf1dbbb258f3718f4e4ce`
- `ride` — `design/e6_final_exterior/step_anchored_v2/class_a_cad/controlled_source_e6_dfr5/workcore_e6_dfr5_ride.glb` — SHA256 `b62bbdae5e02e021d79ef2f2ba0be6a9d4b91ef05e312a45ab319f887a1568ec`
- `cafe` — `design/e6_final_exterior/step_anchored_v2/class_a_cad/controlled_source_e6_dfr5/workcore_e6_dfr5_cafe.glb` — SHA256 `82d738ca716921983252c8ffc5499faa389b6d05920b1090f8edc58e60891f1f`
- `focus` — `design/e6_final_exterior/step_anchored_v2/class_a_cad/controlled_source_e6_dfr5/workcore_e6_dfr5_focus.glb` — SHA256 `ffea83de6d37021cb7a62b8be6013cf2f94410c366ebc10592ebdce3f215d1cb`

## Follow occurrence ledger

| Source occurrence | Disposition | Final responsibility | Rationale |
|---|---|---|---|
| `armrest_base_shell_left` | `replace_surface` | `A05_armrest_table_bay_shell_left` | The prototype left armrest base shell gives way to the continuous final A05 wing surface. |
| `armrest_base_shell_right` | `replace_surface` | `A05_armrest_table_bay_shell_right` | The prototype right armrest base shell gives way to the continuous final A05 wing surface. |
| `armrest_lid_left` | `replace_surface` | `A05_armrest_touch_lid_left` | The prototype left armrest lid gives way to the continuous final A05 wing surface. |
| `armrest_lid_right` | `replace_surface` | `A05_armrest_touch_lid_right` | The prototype right armrest lid gives way to the continuous final A05 wing surface. |
| `armrest_shell_left` | `replace_surface` | `A05_armrest_table_bay_shell_left` | The prototype left armrest shell gives way to the continuous final A05 wing surface. |
| `armrest_shell_right` | `replace_surface` | `A05_armrest_table_bay_shell_right` | The prototype right armrest shell gives way to the continuous final A05 wing surface. |
| `armrest_transfer_hinge_right` | `trace_only_retired` | immutable trace underlay only; absent from production BOM and final render | armrest_transfer_hinge_right belongs to the deleted side-opening prototype and remains only in the immutable trace underlay; the fixed-armrest production configuration contains no corresponding hinge or link. |
| `armrest_transfer_hinge_shroud_right` | `replace_surface` | `A05_armrest_table_bay_shell_right` | armrest_transfer_hinge_shroud_right is a prototype transfer shroud removed in favour of the fixed continuous right A05 wing; no side-opening seam or control remains in the final exterior. |
| `armrest_transfer_link_right` | `trace_only_retired` | immutable trace underlay only; absent from production BOM and final render | armrest_transfer_link_right belongs to the deleted side-opening prototype and remains only in the immutable trace underlay; the fixed-armrest production configuration contains no corresponding hinge or link. |
| `armrest_transfer_link_shroud_right` | `replace_surface` | `A05_armrest_table_bay_shell_right` | armrest_transfer_link_shroud_right is a prototype transfer shroud removed in favour of the fixed continuous right A05 wing; no side-opening seam or control remains in the final exterior. |
| `armrest_transfer_positive_lock_right` | `trace_only_retired` | immutable trace underlay only; absent from production BOM and final render | The controlled transfer lock belongs to the deleted side-opening prototype and remains only in the immutable trace underlay; it is absent from the fixed-armrest production BOM and final render. |
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

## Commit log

2026-08-21 Add WorkCore design assets chunk 01
    [workcore_e6_dfr4_cafe_footrest_open.step]
2026-08-21 Add WorkCore design assets chunk 02
    [workcore_e6_dfr4_cafe.step, workcore_e6_dfr4_focus.step, workcore_e6_dfr4_focus_footrest_open.step]
2026-08-21 Add WorkCore design assets chunk 03
    [workcore_e6_dfr4_follow.step, workcore_e6_dfr4_ride.step, workcore_e6_dfr5_cafe_footrest_open.step]
2026-08-21 Add WorkCore design assets chunk 04
    [workcore_e6_dfr5_cafe.step, workcore_e6_dfr5_focus.step, workcore_e6_dfr5_focus_footrest_open.step]
2026-08-21 Add WorkCore design assets chunk 05
    [e6_v11_v8_locked_reference_master.blend, workcore_e6_dfr5_follow.step, workcore_e6_dfr5_ride.step]
2026-08-21 Add WorkCore design assets chunk 06
    [workcore_e6_v11_cafe_r14.blend, workcore_e6_v11_focus_r14.blend, workcore_e6_v11_follow_r14.blend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]
